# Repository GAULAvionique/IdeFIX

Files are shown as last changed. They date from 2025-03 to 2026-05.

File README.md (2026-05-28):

MasterHead (https://gaulspace.web.app/home)

<h1 align="center">Ordinateur de bord GAUL 2024-2025</h1>



<p align="left">
  <a href="https://www.facebook.com/gaul.ul" target="_blank">
    GAUL Facebook
  </a>
  <a href="https://www.instagram.com/gaul.ul/" target="_blank">
    GAUL Instagram
  </a>
  <a href="https://www.facebook.com/groupeaerospatialul/" target="_blank">
    GAUL Youtube
  </a>
</p>

## 🌟 **Projet IdeFIX**

IdeFIX est une **balise de repérage embarquée** développée par le GAUL afin de faciliter la récupération et le suivi d’équipements après mission. Le système agit comme une plateforme compacte de télémétrie et de localisation capable de transmettre des informations essentielles en temps réel.

Le projet est conçu pour être :

* Léger et robuste
* Facilement intégrable dans une charge utile ou une fusée
* Optimisé pour une faible consommation énergétique
* Modulable selon les besoins de mission

L’objectif principal d’IdeFIX est d’assurer un repérage fiable des systèmes embarqués pendant les phases de récupération à courte distance.

---

## 📦 **Fonctionnalités Intégrées**

Le système se subdivise en deux cartes qui peuvent inclure plusieurs modules matériels et logiciels :

* **Communication Radio**

  Transmission des données vers une station sol pour le suivi et la récupération.

* **Microcontrôleur principal**

  Assure le traitement des données, la gestion des capteurs et les communications.

* **Gestion d’alimentation**

  Système optimisé pour maximiser l’autonomie et assurer la stabilité électrique.

* **Indicateurs de statut**

  LEDs, buzzer ou autres systèmes de rétroaction pour le diagnostic et le déboggage.

---

## 🛰 **Architecture du Projet**

Le dépôt contient l’ensemble des éléments nécessaires au développement de la balise :

* Firmware embarqué
* Drivers matériels
* Configuration des périphériques
* Documentation technique
* Outils de test et validation
* Scripts utilitaires

L’architecture logicielle vise à simplifier le développement et permettre une maintenance efficace du système.

---

## 📷 **Images du Projet**

Découvrez les différentes itérations et prototypes de la balise de repérage :

[Voir la Showcase](./Documentation/Showcase.md)

<div style="display: flex; justify-content: space-around;">
  PCB IdeFIX
  Prototype IdeFIX
</div>

---

## 📚 **Documentation**

La documentation complète du projet est disponible dans le dossier `Documentation/`.

### Documentation matérielle

* [Composantes](./Documentation/Composantes.md)
* [Schémas](./Documentation/Schemas.md)
* [Assemblage](./Documentation/Assemblage.md)

### Documentation logicielle

* [Architecture logicielle](./Documentation/Architecture.md)
* [Drivers](./Documentation/Drivers.md)
* [Configuration](./Documentation/Configuration.md)
* [Prise en main](./Documentation/Logiciel.md)

### Développement

* [Guide de contribution](./Documentation/Contribution.md)
* [Tests et validation](./Documentation/Validation.md)

---

## ⚙ **Compilation et Déploiement**

Le projet est développé autour de l’écosystème STM32.

### Environnement recommandé

* STM32CubeIDE
* STM32CubeMX
* GCC ARM Toolchain

### Compilation

```bash
git clone https://github.com/GAULAvionique/IdeFIX.git
```

Ouvrir ensuite le projet dans STM32CubeIDE et compiler le firmware selon la configuration cible.

---

## 🛠 **Roadmap**

Fonctionnalités prévues et améliorations futures :

* Optimisation de la consommation énergétique
* Intégration LoRa longue portée
* Système de récupération automatique
* Interface de télémétrie améliorée
* Intégration de nouveaux capteurs
* Outils de visualisation des données

Consultez la [roadmap](./Documentation/Roadmap.md) pour plus de détails.

---

## 💡 **Liens Utiles**

* [STM32CubeIDE](https://www.st.com/en/development-tools/stm32cubeide.html)
* [Documentation STM32](https://www.st.com/)
* [Tutoriels STM32 — DeepBlueEmbedded](https://deepbluembedded.com/stm32-arm-programming-tutorials/)
* [GAUL](https://gaulspace.web.app/home)

---

## 👥 **Auteurs et Contributeurs**

* [@vides119](https://github.com/vides119)
* [@SamLol12](https://github.com/SamLol12)
* [Contributeurs GAUL](./Documentation/Participants.md)

---

🏠 Retour au la [page d'accueil](https://github.com/GAULAvionique2024-2025)

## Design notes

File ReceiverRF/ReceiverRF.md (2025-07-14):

## Repo technique pour le Receiver RF

Ce dossier contient tous les documents techniques relatifs à la conception du receiver RF.
Soit les librairies KiCad, les schématics KiCad, ainsi que le code.

TODO:
- [X] Footprint correct cristal ***
- [X] Logic converter 3V3 - 5V
- [X] UART out
- [X] Header correct
- [X] Remplacer header par connecteurs?
- [X] vrai interrupteur
- [X] Reverse polarity protection
- [X] Board essentiel + board interface
- [X] Vérifier alimentation

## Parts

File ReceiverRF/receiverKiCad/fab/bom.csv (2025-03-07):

Reference | Value | Digikey | Qty | DNP
Y1 | CTX853CT-ND | CTX853CT-ND | 1
U4 | MLX90393SLW-ABA-011-RE | MLX90393SLW-ABA-011-RECT-ND | 1
U3 | NJM2882F05-TE1 | 2129-NJM2882F05-TE1CT-ND | 1
U2 | NCV5501DT33RKG | NCV5501DT33RKGOSCT-ND | 1
U1 | STM32F103RET6 | 497-6444-ND | 1
S_R4 | 10R | RMCF1206FT10R0CT-ND | 1
RV1 | RK09K1130A5R | PTV09A-4025S-A103-ND | 1
Q1 | MMBT3904 | MMBT3904LT1GOSCT-ND | 1
PWR_D1,PWR_D2 | LTST-C190EKT | 160-1182-1-ND | 2
PWR_C5,S_C7 | 10nF | 311-1174-1-ND | 2
PWR_C2 | 4.7uF | 1276-3182-1-ND | 1
PWR_C1,STM_C6 | 10uF | 2679-AGC1206X6S250-106KXETR-ND | 2
MLX_C3,PWR_C3,STM_C8,STM_C9 | 1uF | 1276-1068-1-ND | 4
MLX_C1,MLX_C2,PWR_C4,STM_C1,STM_C3,STM_C4,STM_C5,S_C2,S_C10 | 100nF | 399-C1206C104K5RACTUCT-ND | 9
LED_R1,LED_R2,LED_R3,PWR_R1,PWR_R2,PWR_R3,PWR_R4 | 145R | 2019-RN73H2BTTD1450F100CT-ND | 7
J1 | RF2-03E-T-00-50-G | 2057-RF2-03E-T-00-50-G-ND | 1
FB1 | ILBB0603ER121V | 541-2290-1-ND | 1
D1,D2,D3 | LTST-C170GKT | 160-1179-1-ND | 3
CSTL_C1,CSTL_C2 | 16pF | 399-CBR06C160F5GACCT-ND | 2
BZ1 | SMTB-0927-TW-R | 668-SMTB-0927-TW-RCT-ND | 1
BUZ_R2,STM_R2 | 1k5 | 541-4184-1-ND | 2
BUZ_R1 | 50R | 541-TNPW120650R0BEENCT-ND | 1
BUZ_D1 | BAT54T1G | BAT54T1GOSCT-ND | 1
BUT_R1,BUT_R2,BUT_R4,I2C_R1,I2C_R2,MLX_R1,MLX_R2,STM_R3,S_R1 | 10k | 311-10.0KFRCT-ND | 9

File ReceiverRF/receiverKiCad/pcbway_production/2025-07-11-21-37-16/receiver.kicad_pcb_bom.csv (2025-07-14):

Designator | Quantity | Value | Footprint | Package | MPN | DNP | Mount_Type | Digikey | Description | Sim.Device | Sim.Type | Sim.Pins
BUT_R1, BUT_R2, BUT_R3, BUT_R4, I2C_R1, I2C_R2, LLS_R2, MLX_R1, MLX_R2, STM_R3, S_R1 | 11 | 10k | R_1206_3216Metric |  |  |  | smt | 311-10.0KFRCT-ND
BUZ_D1 | 1 | BAT54T1G | D_SOD-123 |  |  |  | smt | BAT54T1GOSCT-ND
BUZ_R1 | 1 | 50R | R_1206_3216Metric |  |  |  | smt | 541-TNPW120650R0BEENCT-ND
BUZ_R2, STM_R2 | 2 | 1k5 | R_1206_3216Metric |  |  |  | smt | 541-4184-1-ND
BZ1 | 1 | SMTB-0927-TW-R | Buzzer_D14mm_H7mm_P10mm |  |  |  | tht | 668-SMTB-0927-TW-RCT-ND | SMTB-0927-TW-R
CSTL_C1, CSTL_C2 | 2 | 16pF | C_0603_1608Metric_Pad1.08x0.95mm_HandSolder |  |  |  | smt | 399-CBR06C160F5GACCT-ND
D1 | 1 | SZMMSZ4679T1G | D_MiniMELF |  |  |  | smt | SZMMSZ4679T1GOSCT-ND | 18V, 500mW, 5%, Zener diode, MiniMELF
D2, D3, D4 | 3 | LTST-C170GKT | LTST-C170GKT |  |  |  | smt | 160-1179-1-ND
FB1 | 1 | ILBB0603ER121V | Ferrite_0603 |  |  |  | smt | 541-2290-1-ND | 120 ohm @ 100 MHz
HOLES1, HOLES2 | 2 | Mounting_holes | Mounting_holes |  |  |  | smt
HOLES3 | 1 | Mounting_holes_big | Mounting_holes_big |  |  |  | smt
IF1, IF2 | 2 | ~ | CONN10_530481010_MOL |  |  |  | tht | WM1750-ND
J1 | 1 | RF2-03E-T-00-50-G | SMA_90deg |  |  |  | tht | 2057-RF2-03E-T-00-50-G-ND
J2 | 1 | Conn_01x05_Socket | PinHeader_1x05_P2.54mm_Vertical |  |  |  | tht
J3 | 1 | Conn_01x02_Socket | PinHeader_1x02_P2.54mm_Vertical |  |  |  | tht |  | Generic connector, single row, 01x02, script generated
J4 | 1 | Conn_01x04 | PinHeader_1x04_P2.54mm_Vertical |  |  |  | tht
JP1 | 1 | SolderJumper_2_Open | SolderJumper-2_P1.3mm_Open_TrianglePad1.0x1.5mm |  |  |  | tht
LED_R1, LED_R2, LED_R3, PWR_R1, PWR_R2, PWR_R3, PWR_R4 | 7 | 145R | R_1206_3216Metric |  |  |  | smt | 2019-RN73H2BTTD1450F100CT-ND
LLS_C1, LLS_C2, MLX_C1, MLX_C2, PWR_C4, STM_C1, STM_C3, STM_C4, STM_C5, S_C10, S_C2 | 11 | 100nF | C_1206_3216Metric |  |  |  | smt | 399-C1206C104K5RACTUCT-ND
MLX_A0, MLX_A1 | 2 | jumper | SolderJumper-2_P1.3mm_Open_TrianglePad1.0x1.5mm |  |  |  | tht
MLX_C3, PWR_C3, STM_C8, STM_C9 | 4 | 1uF | C_1206_3216Metric |  |  |  | smt | 1276-1068-1-ND
PWR_C1, STM_C6 | 2 | 10uF | C_1206_3216Metric |  |  |  | smt | 2679-AGC1206X6S250-106KXETR-ND
PWR_C2 | 1 | 4.7uF | C_1206_3216Metric |  |  |  | smt | 1276-3182-1-ND
PWR_C5, S_C7 | 2 | 10nF | C_1206_3216Metric |  |  |  | smt | 311-1174-1-ND
PWR_D1, PWR_D2 | 2 | LTST-C190EKT | LTST-C190EKT |  |  |  | smt | 160-1182-1-ND
PWR_J1 | 1 | Conn_01x02 | PinHeader_1x02_P2.54mm_Vertical |  |  |  | tht
PWR_R5 | 1 | 100k | R_1206_3216Metric |  |  |  | smt | 541-100KUTR-ND
Q1 | 1 | MMBT3904 | SOT-23 |  |  |  | smt | MMBT3904LT1GOSCT-ND | MMBT3904 | NPN | GUMMELPOON | 1=C 2=B 3=E
Q2 | 1 | NTR4101PT1G | SOT-23 |  |  |  | smt | NTR4101PT1GOSCT-ND | P-MOSFET transistor, drain/source/gate | PMOS | VDMOS | 1=D 2=G 3=S
RF1 | 1 | RFM22B | RFM22b-S2_TH |  |  |  | smt
RV1 | 1 | RK09K1130A5R | Potentiometer_Alps_RK09K_Single_Vertical |  |  |  | tht | PTV09A-4025S-A103-ND | RK09K1130A5R
SW1, SW2, SW3, SW4 | 4 | SW_Push | SW_PUSH_6mm_H4.3mm |  |  |  | tht | EG1862-ND
SW5 | 1 | SW_SPDT | CS12ANW03_NKK |  |  |  | tht | 360-2131-ND | Switch, single pole double throw
S_R4 | 1 | 10R | R_1206_3216Metric |  |  |  | smt | RMCF1206FT10R0CT-ND
U1 | 1 | STM32F103RET6 | LQFP64-10x10mm |  |  |  | smt | 497-6444-ND
U2 | 1 | NCV5501DT33RKG | DPAK-3_ONS-M |  |  |  | smt | NCV5501DT33RKGOSCT-ND
U3 | 1 | NJM2882F05-TE1 | SOT-23-5 |  |  |  | smt | 2129-NJM2882F05-TE1CT-ND
U4 | 1 | MLX90393SLW-ABA-011-RE | QFN-16_MLX90393_MEL-L |  |  |  | smt | MLX90393SLW-ABA-011-RECT-ND
U5 | 1 | TXS0102DCUR | SOP50P310X90-8N |  |  |  | smt | 296-21931-2-ND
Y1 | 1 | CTX853CT-ND | Crystal |  |  |  | smt | CTX853CT-ND | 406C35D08M00000

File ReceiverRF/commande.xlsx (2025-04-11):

NOM | I (mA) | QTE | PRIX | DESCRIPTION | LIEN | Coût total
MLX90393 | 1.75 | 1 | 2.85 | bousolle | https://www.digikey.com/en/products/detail/melexis-technologies-nv/MLX90393SLW-ABA-011-RE/5031684 | 100.88453
RFM22B-S2 | 18.5 | 2 | 18.52 | transceiver rf | https://www.xonelec.com/mpn/hopemicroelectronics/rfm22b433s2 | .
STM32F103RET6 | 150 | 1 | 17.33 | MCU | https://www.digikey.ca/en/products/detail/stmicroelectronics/STM32F103RET6/1852094?gad_source=1 | .
NCV5501DT33RKG | -500 | 1 | 1.53 | régulateur 3,3V | https://www.digikey.ca/en/products/detail/onsemi/NCV5501DT33RKG/1792725 | .
NJM2882F05 | 300 | 1 | 1.1 | régulateur 5V | https://www.digikey.ca/en/products/detail/nisshinbo-micro-devices-inc/NJM2882F05-TE1/10671911 | .
CN0296D | 100 | 1 | 20.82 | écran LCD | https://www.digikey.ca/en/products/detail/sunfounder/CN0296D/18668625?gad_source=1 | .
SMTB-0927-TW-R | 80 | 1 | 1.27 | buzzer | https://www.digikey.com/en/products/detail/pui-audio-inc/SMTB-0927-TW-R/13165907 | .
LTST-C170GKT | 10 | 3 | 0.24 | led verte | https://www.digikey.com/en/products/detail/liteon/LTST-C170GKT/269226 | .
LTST-C190EKT | 10 | 2 | 0.34 | led rouge | https://www.digikey.ca/en/products/detail/liteon/LTST-C190EKT/269229?productid=&gad_source=1 | .
L101011MS02Q |  | 1 | 3.73 | interrupteur on/off | https://www.digikey.ca/en/products/detail/c-k/L101011MS02Q/484142 | .
PTV09A-4025S-A103 |  | 1 | 1.09 | potentiomètre | https://www.digikey.ca/en/products/detail/bourns-inc/PTV09A-4025S-A103/3820578 | .
TL1105T | 6 | 4 |  | bouton | https://www.digikey.ca/en/products/detail/c-k/D102J12S215PQA/768267 | .
ILBB0603ER121V | 150 | 1 | 0.16 | ferrite bead | https://www.digikey.ca/en/products/detail/vishay-dale/ILBB0603ER121V/2574888 | .
YG8M000000S418 |  | 1 | 1.85 | Cristal 8MHz | https://www.digikey.ca/en/products/detail/nextgen-components/YG8M000000S418/17289334 | .
RF2-03E-T-00-50-G |  | 1 | 4.19 | Connecteur SMA 90deg | https://www.digikey.ca/en/products/detail/adam-tech/RF2-03E-T-00-50-G/9831386 | .
MMBT3904 |  | 1 | 0.12 | Transistor NPN | https://www.digikey.ca/en/products/detail/onsemi/MMBT3904LT1G/1139813 | .
BAT54T1G |  | 1 | 0.13 | Diode schottky | https://www.digikey.ca/en/products/detail/onsemi/BAT54T1G/918319 | .
 |  |  |  |  |  | .
 |  | 1 | 0.28 | cond 4,7u | https://www.digikey.ca/en/products/detail/samsung-electro-mechanics/CL31B475KOHNNNE/3888840 | . | 1206(3216)
 |  | 2 | 0.09306 | cond 10u | https://www.digikey.ca/en/products/detail/venkel/AGC1206X6S250-106KXE/20484934 | . | 1206(3216)
 |  | 4 | 0.01806 | cond 1u | https://www.digikey.ca/en/products/detail/samsung-electro-mechanics/CL31B105KBHNNNE/3886726 | . | 1206(3216)
 |  | 9 | 0.00805 | cond 100n | https://www.digikey.ca/en/products/detail/kemet/C1206C104K5RACTU/411248 | . | 1206(3216)
 |  | 2 | 0.00186 | cond 10n | https://www.digikey.ca/en/products/detail/yageo/CC1206KRX7R9BB103/302908 | . | 1206(3216)
 |  | 2 | 0.33 | cond 16p | https://www.digikey.ca/en/products/detail/kemet/CBR06C160F5GAC/3473742 | . | 0603(1608)
 |  |  |  |  |  | .
 |  | 9 | 0.1 | res 10k | https://www.digikey.ca/en/products/detail/yageo/RC1206FR-0710KL/728483 | . | 1206(3216)
 |  | 1 | 0.1 | res 10 | https://www.digikey.ca/en/products/detail/stackpole-electronics-inc/RMCF1206FT10R0/1759594 | . | 1206(3216)
 |  | 1 | 0.91 | res 50 (100mA) | https://www.digikey.ca/en/products/detail/vishay-dale/TNPW120650R0BEEN/21556504 | . | 1206(3216)
 |  | 2 | 0.18 | res 1k5 | https://www.digikey.ca/en/products/detail/vishay-dale/CRCW12061K50FKEAC/7928606 | . | 1206(3216)
 |  | 7 | 0.39 | res 145 (50mA) | https://www.digikey.ca/en/products/detail/koa-speer-electronics-inc/RN73H2BTTD1450F100/10092754 | . | 1206(3216)
 |  |  |  |  |  | .
 |  |  |  |  |  | .
 |  |  |  |  |  | .
 |  |  |  |  |  | .
 |  |  |  |  |  | .
 |  |  |  |  |  | .
 |  |  |  |  |  | .
 |  |  |  |  |  | .

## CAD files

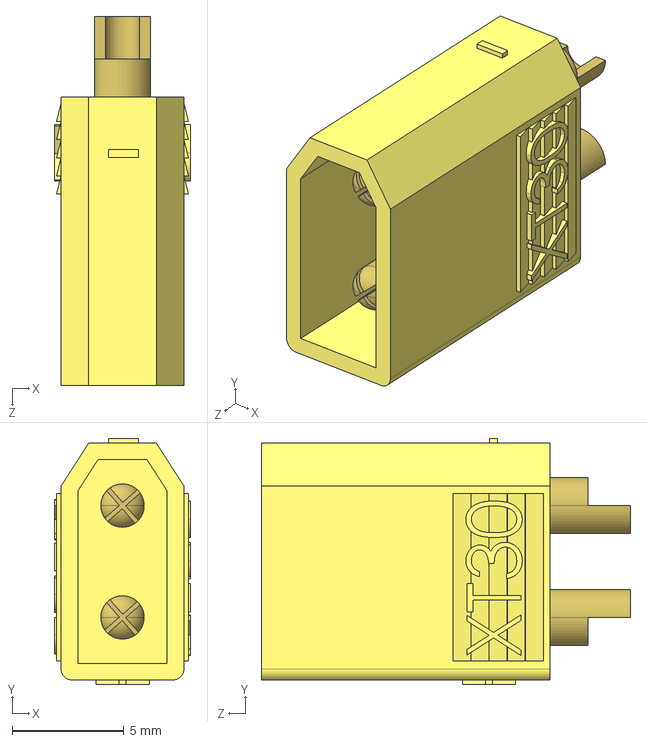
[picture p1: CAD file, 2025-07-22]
ReceiverRF/receiverKiCad/librairie-receiver/lib_3D/XT30-M_m.ver.STEP
6.10 x 11.0 x 16.5 mm

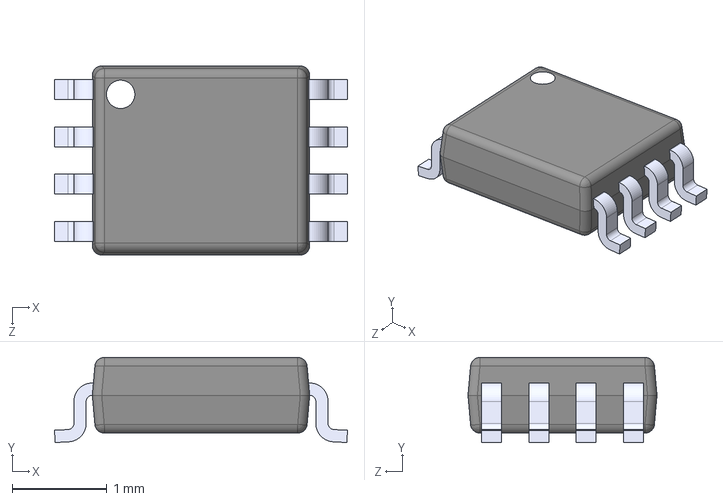
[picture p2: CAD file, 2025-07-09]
ReceiverRF/receiverKiCad/librairie-receiver/lib_3D/TXS0102DCUR.step
3.10 x 0.9 x 2.00 mm

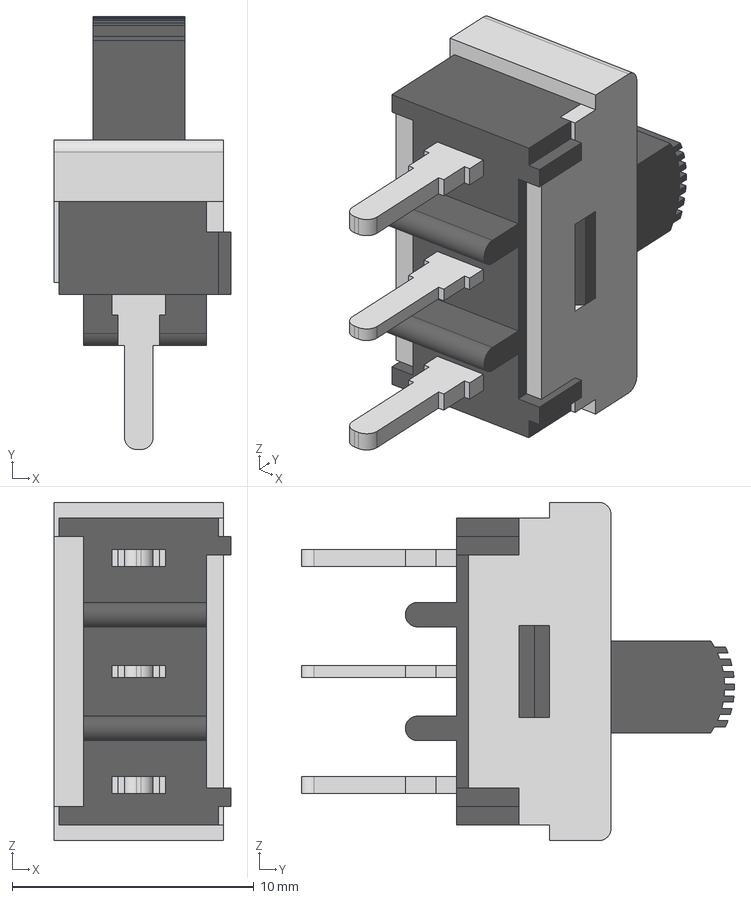
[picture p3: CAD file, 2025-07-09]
ReceiverRF/receiverKiCad/librairie-receiver/lib_3D/CS12ANW03.stp
7.32 x 17.9 x 14.0 mm
CS12ANW03-body
CS12ANW03-top
CS12ANW03-term
CS12ANW03-slide

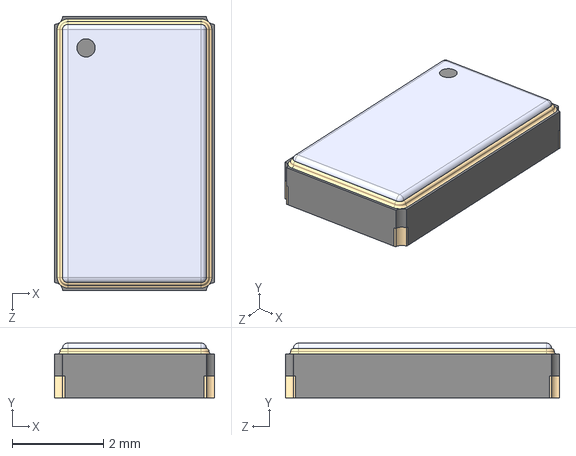
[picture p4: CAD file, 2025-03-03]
ReceiverRF/receiverKiCad/librairie-receiver/lib_3D/406C35D08M00000.STEP
3.50 x 1.20 x 6.00 mm

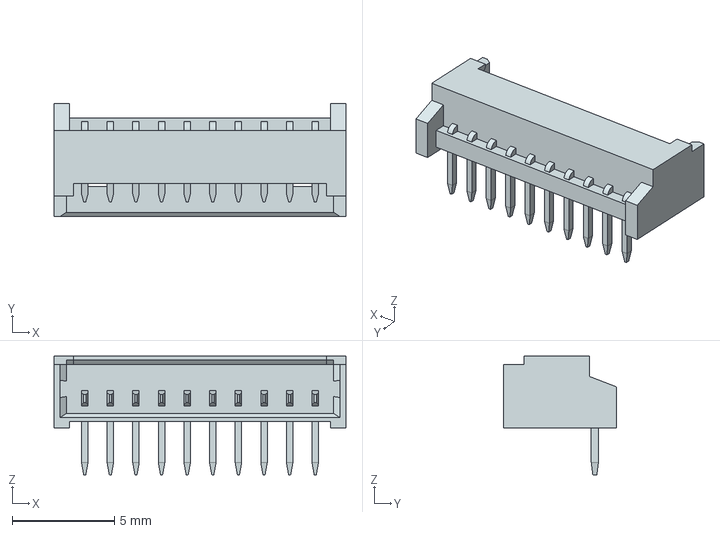
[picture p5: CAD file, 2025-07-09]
ReceiverRF/receiverKiCad/librairie-receiver/lib_3D/530481010.stp
14.2 x 5.50 x 5.80 mm

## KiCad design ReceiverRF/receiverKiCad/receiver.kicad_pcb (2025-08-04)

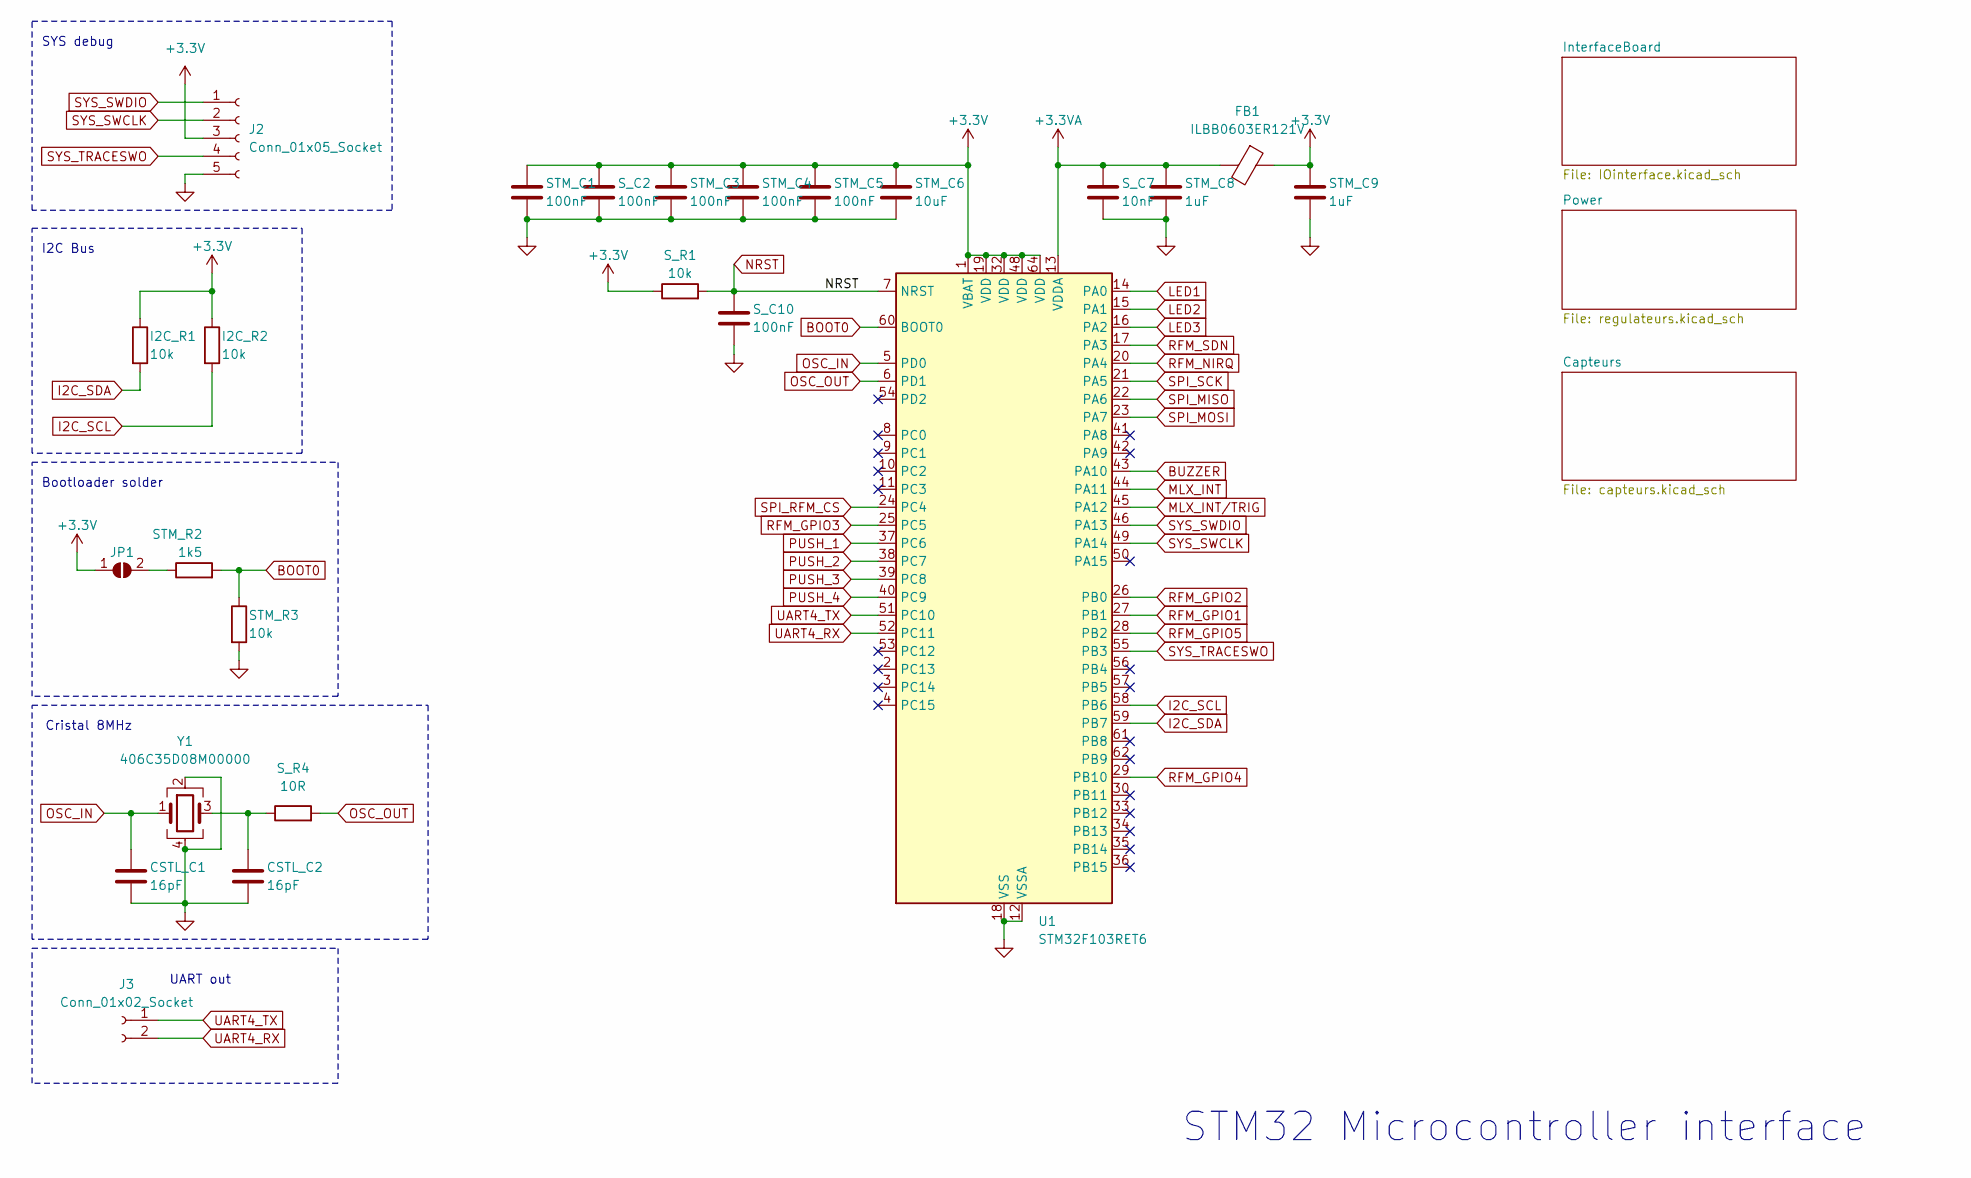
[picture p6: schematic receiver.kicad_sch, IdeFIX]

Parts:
CSTL_C1, CSTL_C2: 16pF; C_0603_1608Metric_Pad1.08x0.95mm_HandSolder; Digikey 399-CBR06C160F5GACCT-ND
FB1: ILBB0603ER121V; Ferrite_0603; Digikey 541-2290-1-ND
I2C_R1, I2C_R2: 10k; R_1206_3216Metric; Digikey 311-10.0KFRCT-ND
J2: Conn_01x05_Socket; PinHeader_1x05_P2.54mm_Vertical
J3: Conn_01x02_Socket; PinHeader_1x02_P2.54mm_Vertical
JP1: SolderJumper_2_Open; SolderJumper-2_P1.3mm_Open_TrianglePad1.0x1.5mm
STM_C1, STM_C3, STM_C4, STM_C5: 100nF; C_1206_3216Metric; Digikey 399-C1206C104K5RACTUCT-ND
STM_C6: 10uF; C_1206_3216Metric; Digikey 1276-1804-1-ND
STM_C8, STM_C9: 1uF; C_1206_3216Metric; Digikey 1276-1068-1-ND
STM_R2: 1k5; R_1206_3216Metric; Digikey 541-4184-1-ND
STM_R3: 10k; R_1206_3216Metric; Digikey 311-10.0KFRCT-ND
S_C2, S_C10: 100nF; C_1206_3216Metric; Digikey 399-C1206C104K5RACTUCT-ND
S_C7: 10nF; C_1206_3216Metric; Digikey 311-1174-1-ND
S_R1: 10k; R_1206_3216Metric; Digikey 311-10.0KFRCT-ND
S_R4: 10R; R_1206_3216Metric; Digikey RMCF1206FT10R0CT-ND
U1: STM32F103RET6; LQFP64-10x10mm; Digikey 497-6444-ND
Y1: 406C35D08M00000; Crystal; Digikey 110-406C35D08M00000CT-ND

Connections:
+3.3V: FB1.1, I2C_R1.1, I2C_R2.1, J2.3, JP1.1 (A), STM_C1.1, STM_C3.1, STM_C4.1, STM_C5.1, STM_C6.1, STM_C9.1, S_C2.1, S_R1.1, U1.1 (VBAT), U1.19 (VDD), U1.32 (VDD), U1.48 (VDD), U1.64 (VDD); also elsewhere on the board
+3.3VA: FB1.2, STM_C8.1, S_C7.1, U1.13 (VDDA)
BOOT0: STM_R2.2, STM_R3.1, U1.60 (BOOT0)
BUZZER: U1.43 (PA10); also elsewhere on the board
GND: CSTL_C1.2, CSTL_C2.2, J2.5, STM_C1.2, STM_C3.2, STM_C4.2, STM_C5.2, STM_C6.2, STM_C8.2, STM_C9.2, STM_R3.2, S_C2.2, S_C7.2, S_C10.2, U1.12 (VSSA), U1.18 (VSS), U1.31 (VSS), U1.47 (VSS), U1.63 (VSS), Y1.2, Y1.4; also elsewhere on the board
I2C_SCL: I2C_R2.2, U1.58 (PB6); also elsewhere on the board
I2C_SDA: I2C_R1.2, U1.59 (PB7); also elsewhere on the board
LED1: U1.14 (PA0); also elsewhere on the board
LED2: U1.15 (PA1); also elsewhere on the board
LED3: U1.16 (PA2); also elsewhere on the board
MLX_INT: U1.44 (PA11); also elsewhere on the board
MLX_INT/TRIG: U1.45 (PA12); also elsewhere on the board
NRST: S_C10.1, S_R1.2, U1.7 (NRST)
unnamed: CSTL_C2.1, S_R4.1, Y1.3
unnamed: JP1.2 (B), STM_R2.1
OSC_IN: CSTL_C1.1, U1.5 (PD0), Y1.1
OSC_OUT: S_R4.2, U1.6 (PD1)
PUSH_1: U1.37 (PC6); also elsewhere on the board
PUSH_2: U1.38 (PC7); also elsewhere on the board
PUSH_3: U1.39 (PC8); also elsewhere on the board
PUSH_4: U1.40 (PC9); also elsewhere on the board
RFM_GPIO1: U1.27 (PB1); also elsewhere on the board
RFM_GPIO2: U1.26 (PB0); also elsewhere on the board
RFM_GPIO3: U1.25 (PC5); also elsewhere on the board
RFM_GPIO4: U1.29 (PB10); also elsewhere on the board
RFM_GPIO5: U1.28 (PB2); also elsewhere on the board
RFM_NIRQ: U1.20 (PA4); also elsewhere on the board
RFM_SDN: U1.17 (PA3); also elsewhere on the board
SPI_MISO: U1.22 (PA6); also elsewhere on the board
SPI_MOSI: U1.23 (PA7); also elsewhere on the board
SPI_RFM_CS: U1.24 (PC4); also elsewhere on the board
SPI_SCK: U1.21 (PA5); also elsewhere on the board
SYS_SWCLK: J2.2, U1.49 (PA14)
SYS_SWDIO: J2.1, U1.46 (PA13)
SYS_TRACESWO: J2.4, U1.55 (PB3)
UART4_RX: J3.2, U1.52 (PC11)
UART4_TX: J3.1, U1.51 (PC10)

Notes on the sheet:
I2C Bus
STM32 Microcontroller interface
Cristal 8MHz
Bootloader solder
SYS debug
UART out

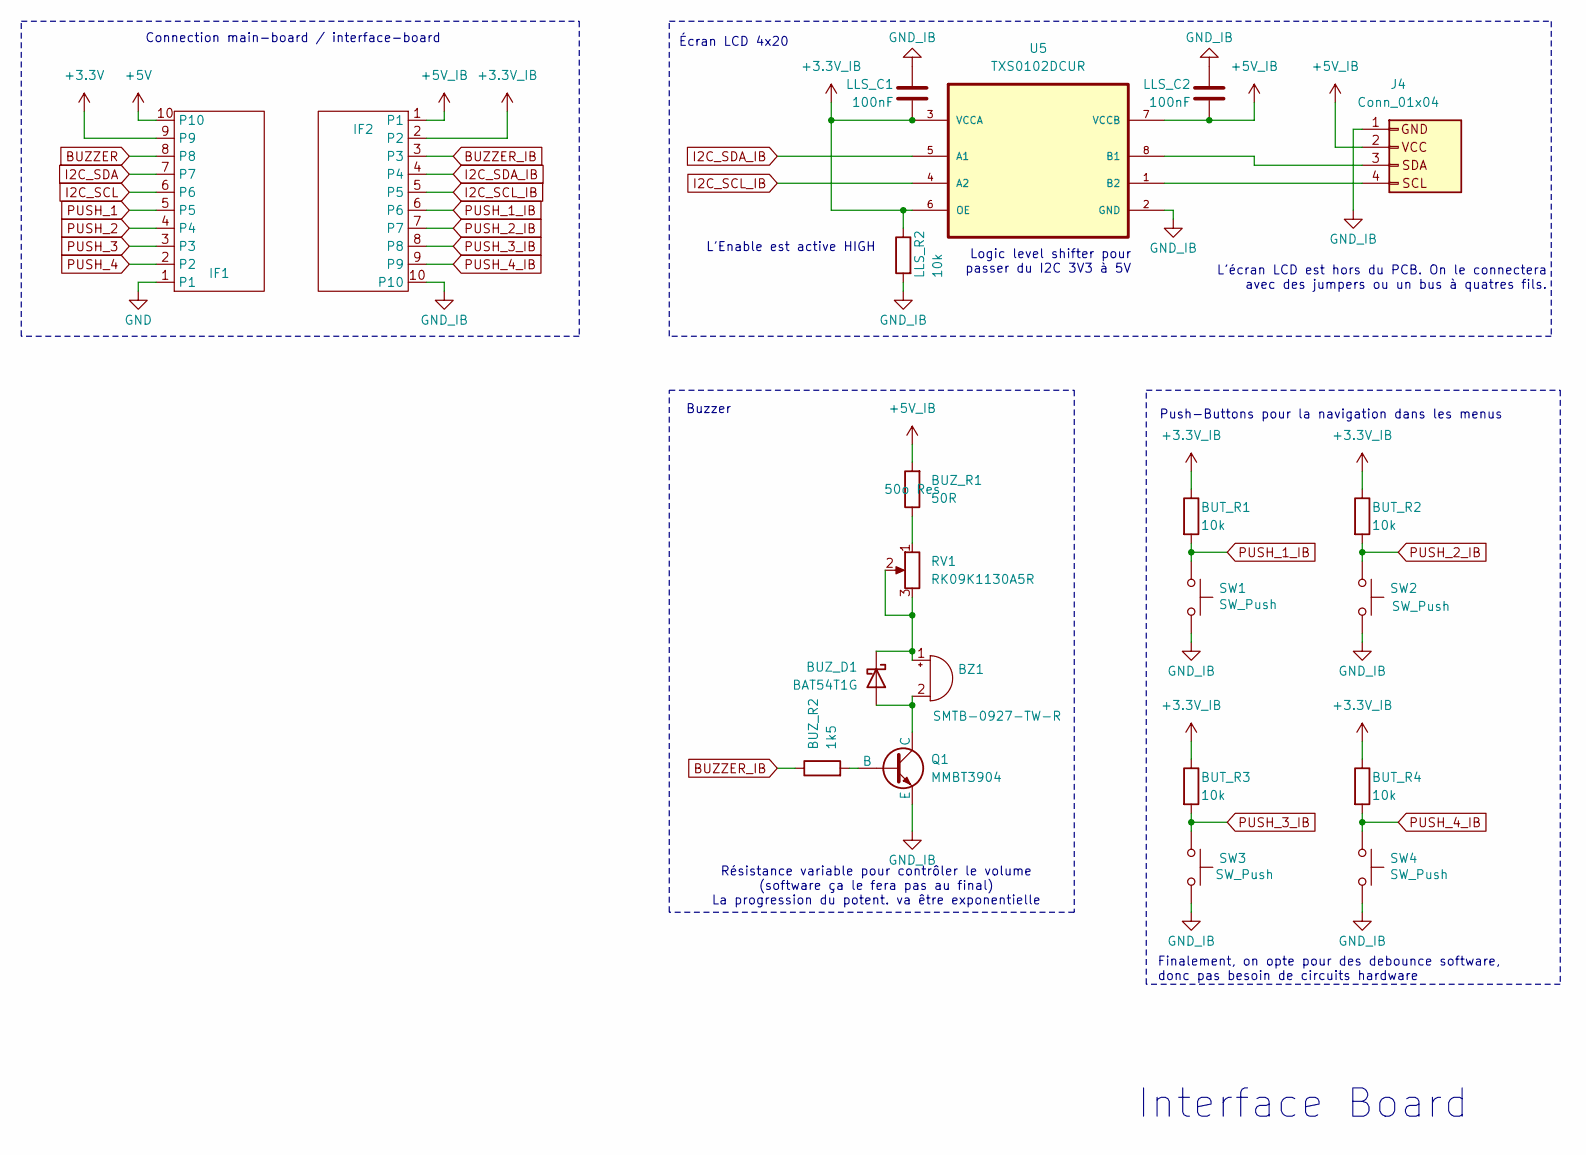
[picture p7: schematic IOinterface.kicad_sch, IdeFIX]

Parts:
BUT_R1, BUT_R2, BUT_R3, BUT_R4: 10k; R_1206_3216Metric; Digikey 311-10.0KFRCT-ND
BUZ_D1: BAT54T1G; D_SOD-123; Digikey BAT54T1GOSCT-ND
BUZ_R1: 50R; R_1206_3216Metric; Digikey 541-TNPW120650R0BEENCT-ND
BUZ_R2: 1k5; R_1206_3216Metric; Digikey 541-4184-1-ND
BZ1: SMTB-0927-TW-R; Buzzer_D14mm_H7mm_P10mm; Digikey 668-SMTB-0927-TW-RCT-ND
IF1, IF2: CONN10_530481010_MOL; Digikey WM1750-ND
J4: Conn_01x04; PinHeader_1x04_P2.54mm_Vertical
LLS_C1, LLS_C2: 100nF; C_1206_3216Metric; Digikey 399-C1206C104K5RACTUCT-ND
LLS_R2: 10k; R_1206_3216Metric; Digikey 311-10.0KFRCT-ND
Q1: MMBT3904; SOT-23; Digikey MMBT3904LT1GOSCT-ND
RV1: RK09K1130A5R; Potentiometer_Alps_RK09K_Single_Vertical; Digikey 4809-RK09K1130A5R-ND
SW1, SW2, SW3, SW4: SW_Push; SW_PUSH_6mm_H4.3mm; Digikey EG1862-ND
U5: TXS0102DCUR; SOP50P310X90-8N; Digikey 296-21931-2-ND

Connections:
+3.3V: IF1.9; also elsewhere on the board
+3.3V_IB: BUT_R1.1, BUT_R2.1, BUT_R3.1, BUT_R4.1, IF2.2, LLS_C1.2, LLS_R2.1, U5.3 (VCCA), U5.6 (OE)
+5V: IF1.10; also elsewhere on the board
+5V_IB: BUZ_R1.2, IF2.1, J4.2 (VCC), LLS_C2.2, U5.7 (VCCB)
BUZZER: IF1.8; also elsewhere on the board
BUZZER_IB: BUZ_R2.1, IF2.3
GND: IF1.1; also elsewhere on the board
GND_IB: IF2.10, J4.1 (GND), LLS_C1.1, LLS_C2.1, LLS_R2.2, Q1.3 (E), SW1.2, SW2.2, SW3.2, SW4.2, U5.2 (GND)
I2C_SCL: IF1.6; also elsewhere on the board
I2C_SCL_IB: IF2.5, U5.4 (A2)
I2C_SDA: IF1.7; also elsewhere on the board
I2C_SDA_IB: IF2.4, U5.5 (A1)
unnamed: BUZ_D1.2 (A), BZ1.2 (+), Q1.1 (C)
unnamed: BUZ_D1.1 (K), BZ1.1 (-), RV1.2, RV1.3
unnamed: BUZ_R1.1, RV1.1
unnamed: J4.4 (SCL), U5.1 (B2)
unnamed: J4.3 (SDA), U5.8 (B1)
unnamed: BUZ_R2.2, Q1.2 (B)
PUSH_1: IF1.5; also elsewhere on the board
PUSH_1_IB: BUT_R1.2, IF2.6, SW1.1
PUSH_2: IF1.4; also elsewhere on the board
PUSH_2_IB: BUT_R2.2, IF2.7, SW2.1
PUSH_3: IF1.3; also elsewhere on the board
PUSH_3_IB: BUT_R3.2, IF2.8, SW3.1
PUSH_4: IF1.2; also elsewhere on the board
PUSH_4_IB: BUT_R4.2, IF2.9, SW4.1

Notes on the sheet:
Logic level shifter pour passer du I2C 3V3 à 5V
Interface Board
Connection main-board / interface-board
L'écran LCD est hors du PCB. On le connectera avec des jumpers ou un bus à quatres fils.
Finalement, on opte pour des debounce software, donc pas besoin de circuits hardware
Écran LCD 4x20
Résistance variable pour contrôler le volume (software ça le fera pas au final) La progression du potent. va être exponentielle
Buzzer
Push-Buttons pour la navigation dans les menus
L'Enable est active HIGH

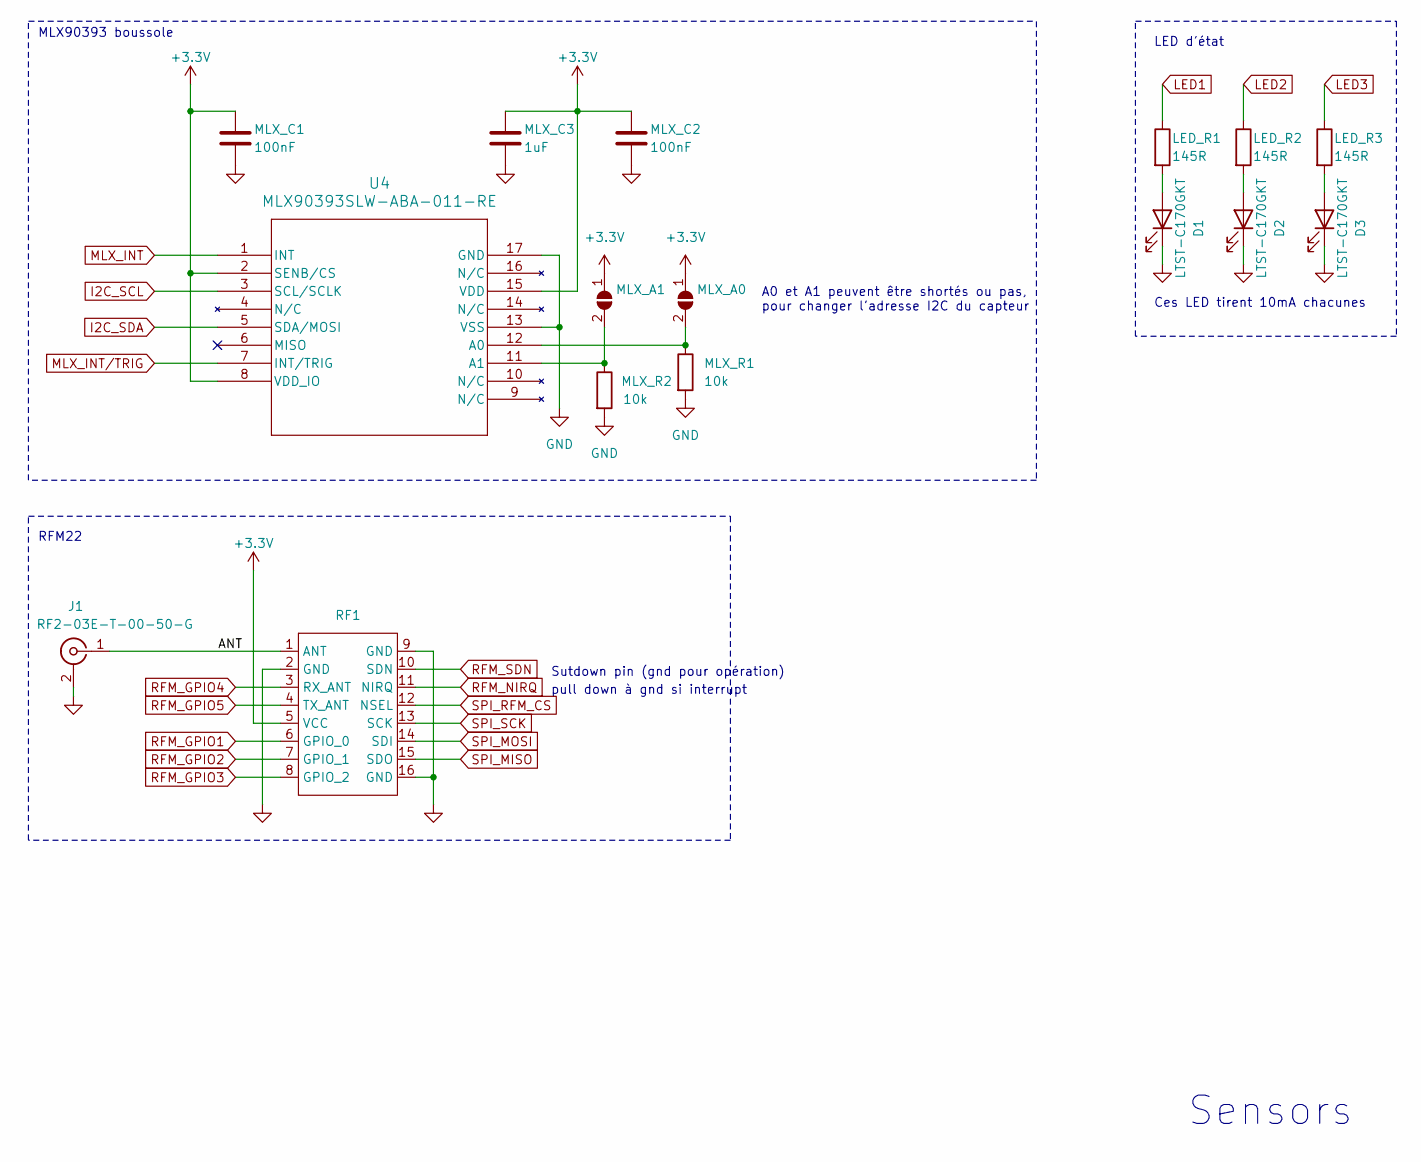
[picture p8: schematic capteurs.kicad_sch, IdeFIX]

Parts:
D1, D2, D3: LTST-C170GKT; Digikey 160-1414-1-ND
J1: RF2-03E-T-00-50-G; SMA_90deg; Digikey 2057-RF2-03E-T-00-50-G-ND
LED_R1, LED_R2, LED_R3: 145R; R_1206_3216Metric; Digikey 2019-RN73H2BTTD1450F100CT-ND
MLX_A0, MLX_A1: jumper; SolderJumper-2_P1.3mm_Open_TrianglePad1.0x1.5mm
MLX_C1, MLX_C2: 100nF; C_1206_3216Metric; Digikey 399-C1206C104K5RACTUCT-ND
MLX_C3: 1uF; C_1206_3216Metric; Digikey 1276-1068-1-ND
MLX_R1, MLX_R2: 10k; R_1206_3216Metric; Digikey 311-10.0KFRCT-ND
RF1: RFM22B; RFM22b-S2_TH
U4: MLX90393SLW-ABA-011-RE; QFN-16_MLX90393_MEL-L; Digikey MLX90393SLW-ABA-011-RECT-ND

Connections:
+3.3V: MLX_A0.1 (A), MLX_A1.1 (A), MLX_C1.1, MLX_C2.1, MLX_C3.1, RF1.5 (VCC), U4.2 (SENB/CS), U4.8 (VDD_IO), U4.15 (VDD); also elsewhere on the board
/Capteurs/ANT: J1.1 (In), RF1.1 (ANT)
GND: D1.1 (K), D2.1 (K), D3.1 (K), J1.2 (Ext), MLX_C1.2, MLX_C2.2, MLX_C3.2, MLX_R1.2, MLX_R2.2, RF1.2 (GND), RF1.9 (GND), RF1.16 (GND), U4.13 (VSS), U4.17 (GND); also elsewhere on the board
I2C_SCL: U4.3 (SCL/SCLK); also elsewhere on the board
I2C_SDA: U4.5 (SDA/MOSI); also elsewhere on the board
LED1: LED_R1.1; also elsewhere on the board
LED2: LED_R2.1; also elsewhere on the board
LED3: LED_R3.1; also elsewhere on the board
MLX_INT: U4.1 (INT); also elsewhere on the board
MLX_INT/TRIG: U4.7 (INT/TRIG); also elsewhere on the board
unnamed: D1.2 (A), LED_R1.2
unnamed: D2.2 (A), LED_R2.2
unnamed: D3.2 (A), LED_R3.2
unnamed: MLX_A0.2 (B), MLX_R1.1, U4.12 (A0)
unnamed: MLX_A1.2 (B), MLX_R2.1, U4.11 (A1)
RFM_GPIO1: RF1.6 (GPIO_0); also elsewhere on the board
RFM_GPIO2: RF1.7 (GPIO_1); also elsewhere on the board
RFM_GPIO3: RF1.8 (GPIO_2); also elsewhere on the board
RFM_GPIO4: RF1.3 (RX_ANT); also elsewhere on the board
RFM_GPIO5: RF1.4 (TX_ANT); also elsewhere on the board
RFM_NIRQ: RF1.11 (NIRQ); also elsewhere on the board
RFM_SDN: RF1.10 (SDN); also elsewhere on the board
SPI_MISO: RF1.15 (SDO); also elsewhere on the board
SPI_MOSI: RF1.14 (SDI); also elsewhere on the board
SPI_RFM_CS: RF1.12 (NSEL); also elsewhere on the board
SPI_SCK: RF1.13 (SCK); also elsewhere on the board

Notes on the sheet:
Ces LED tirent 10mA chacunes
pull down à gnd si interrupt
Sutdown pin (gnd pour opération)
MLX90393 boussole
LED d'état
Sensors
RFM22
A0 et A1 peuvent être shortés ou pas, pour changer l'adresse I2C du capteur

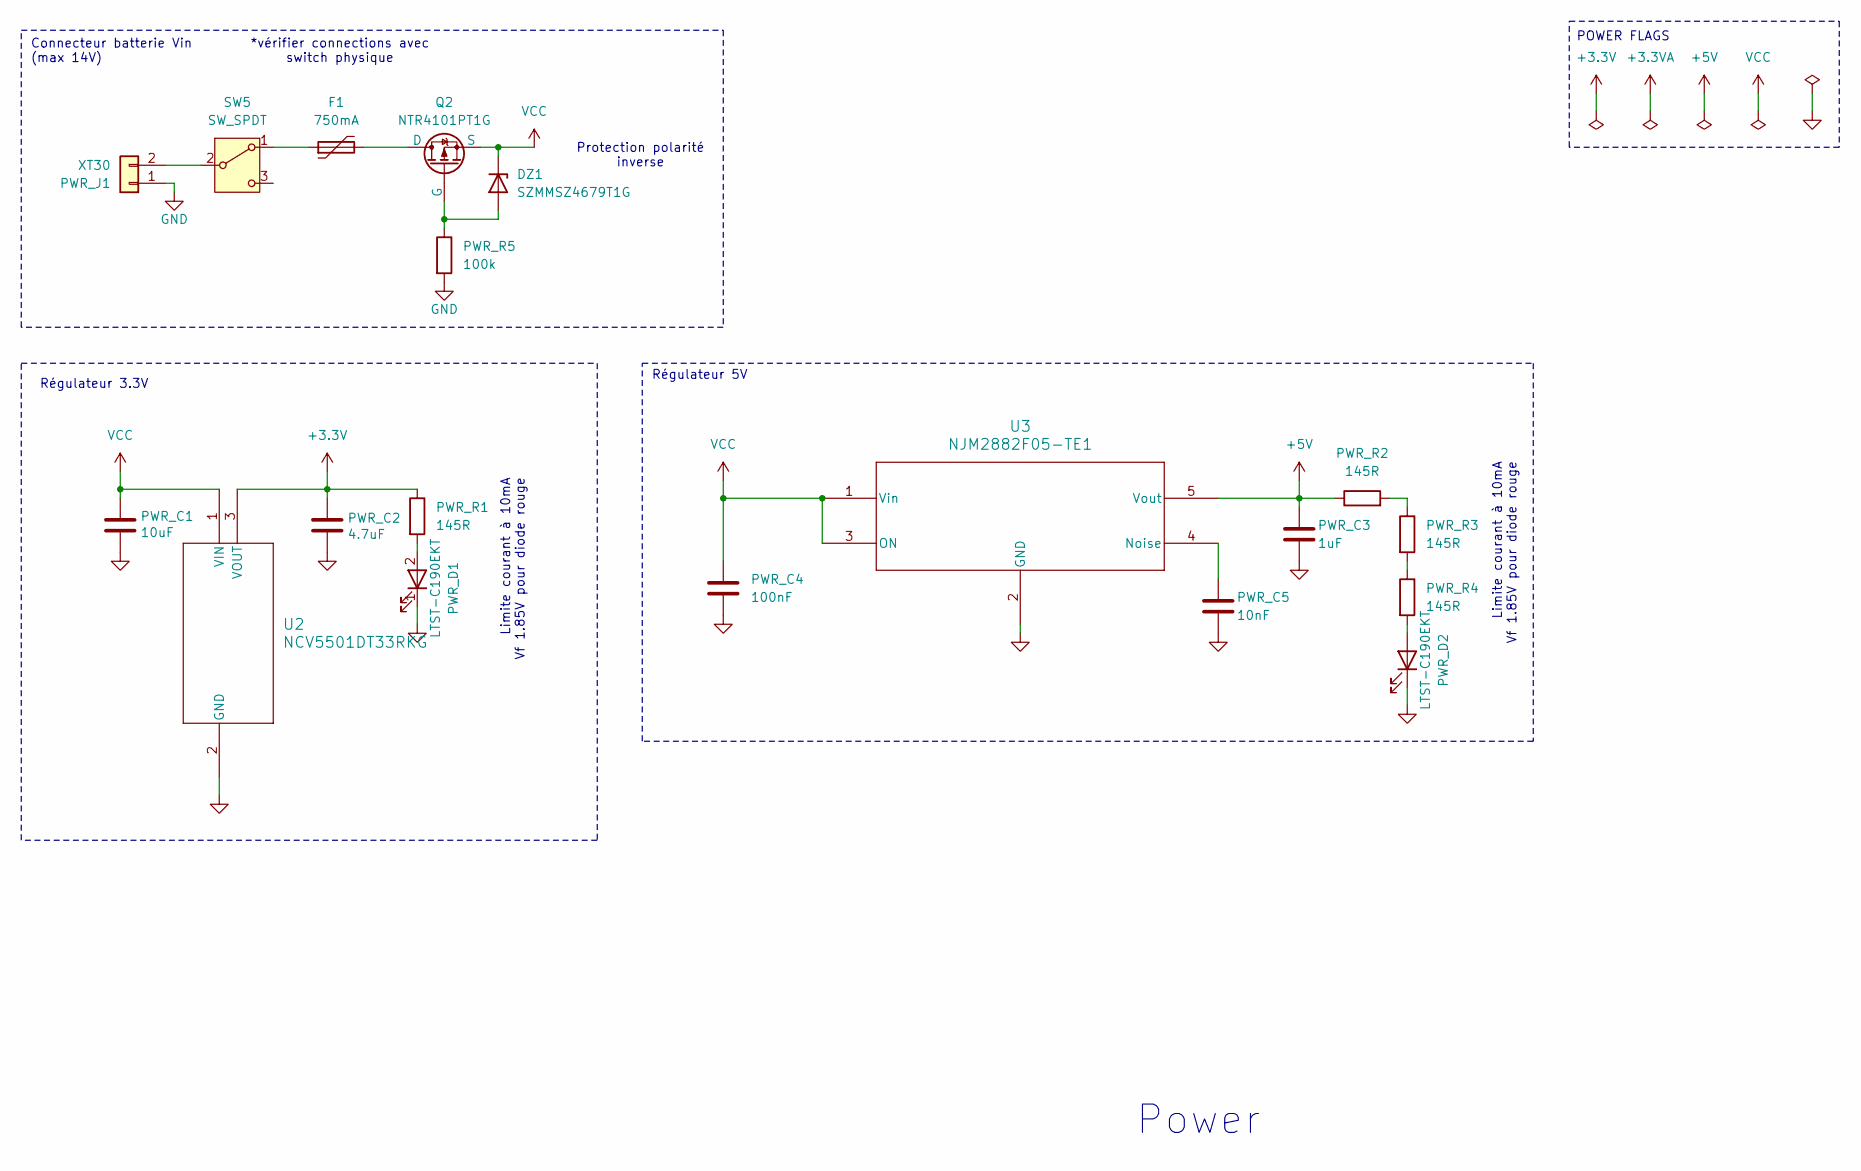
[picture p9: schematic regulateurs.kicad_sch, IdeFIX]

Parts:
DZ1: SZMMSZ4679T1G; D_SOD-123; Digikey SZMMSZ4679T1GOSCT-ND
F1: 750mA; Polyfuse; Digikey 118-MF-NSMF075/13X-2CT-ND
PWR_C1: 10uF; C_1206_3216Metric; Digikey 1276-1804-1-ND
PWR_C2: 4.7uF; C_1206_3216Metric; Digikey 1276-3182-1-ND
PWR_C3: 1uF; C_1206_3216Metric; Digikey 1276-1068-1-ND
PWR_C4: 100nF; C_1206_3216Metric; Digikey 399-C1206C104K5RACTUCT-ND
PWR_C5: 10nF; C_1206_3216Metric; Digikey 311-1174-1-ND
PWR_D1, PWR_D2: LTST-C190EKT; Digikey 516-1422-1-ND
PWR_J1: XT30; AMASS_XT30U-M_1x02_P5.0mm_Vertical; Digikey 1568-10474-ND
PWR_R1, PWR_R2, PWR_R3, PWR_R4: 145R; R_1206_3216Metric; Digikey 2019-RN73H2BTTD1450F100CT-ND
PWR_R5: 100k; R_1206_3216Metric; Digikey 541-100KUCT-ND
Q2: NTR4101PT1G; SOT-23; Digikey NTR4101PT1GOSCT-ND
SW5: SW_SPDT; CS12ANW03_NKK; Digikey 360-2131-ND
U2: NCV5501DT33RKG; DPAK-3_ONS-M; Digikey NCV5501DT33RKGOSCT-ND
U3: NJM2882F05-TE1; SOT-23-5; Digikey 2129-NJM2882F05-TE1CT-ND

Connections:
+3.3V: PWR_C2.1, PWR_R1.1, U2.3 (VOUT); also elsewhere on the board
+5V: PWR_C3.1, PWR_R2.1, U3.5 (Vout); also elsewhere on the board
GND: PWR_C1.2, PWR_C2.2, PWR_C3.2, PWR_C4.2, PWR_C5.2, PWR_D1.1 (K), PWR_D2.1 (K), PWR_J1.1, PWR_R5.2, U2.2 (GND), U3.2 (GND); also elsewhere on the board
unnamed: DZ1.2 (A), PWR_R5.1, Q2.2 (G)
unnamed: PWR_D1.2 (A), PWR_R1.2
unnamed: PWR_D2.2 (A), PWR_R4.2
unnamed: PWR_J1.2, SW5.2 (B)
unnamed: PWR_R2.2, PWR_R3.1
unnamed: PWR_R3.2, PWR_R4.1
unnamed: F1.2, Q2.1 (D)
unnamed: F1.1, SW5.1 (A)
unnamed: PWR_C5.1, U3.4 (Noise)
VCC: DZ1.1 (K), PWR_C1.1, PWR_C4.1, Q2.3 (S), U2.1 (VIN), U3.1 (Vin), U3.3 (ON)

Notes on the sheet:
Limite courant à 10mA Vf 1.85V pour diode rouge
Power
Protection polarité inverse
Connecteur batterie Vin (max 14V)
POWER FLAGS
Régulateur 5V
*vérifier connections avec switch physique
Régulateur 3.3V

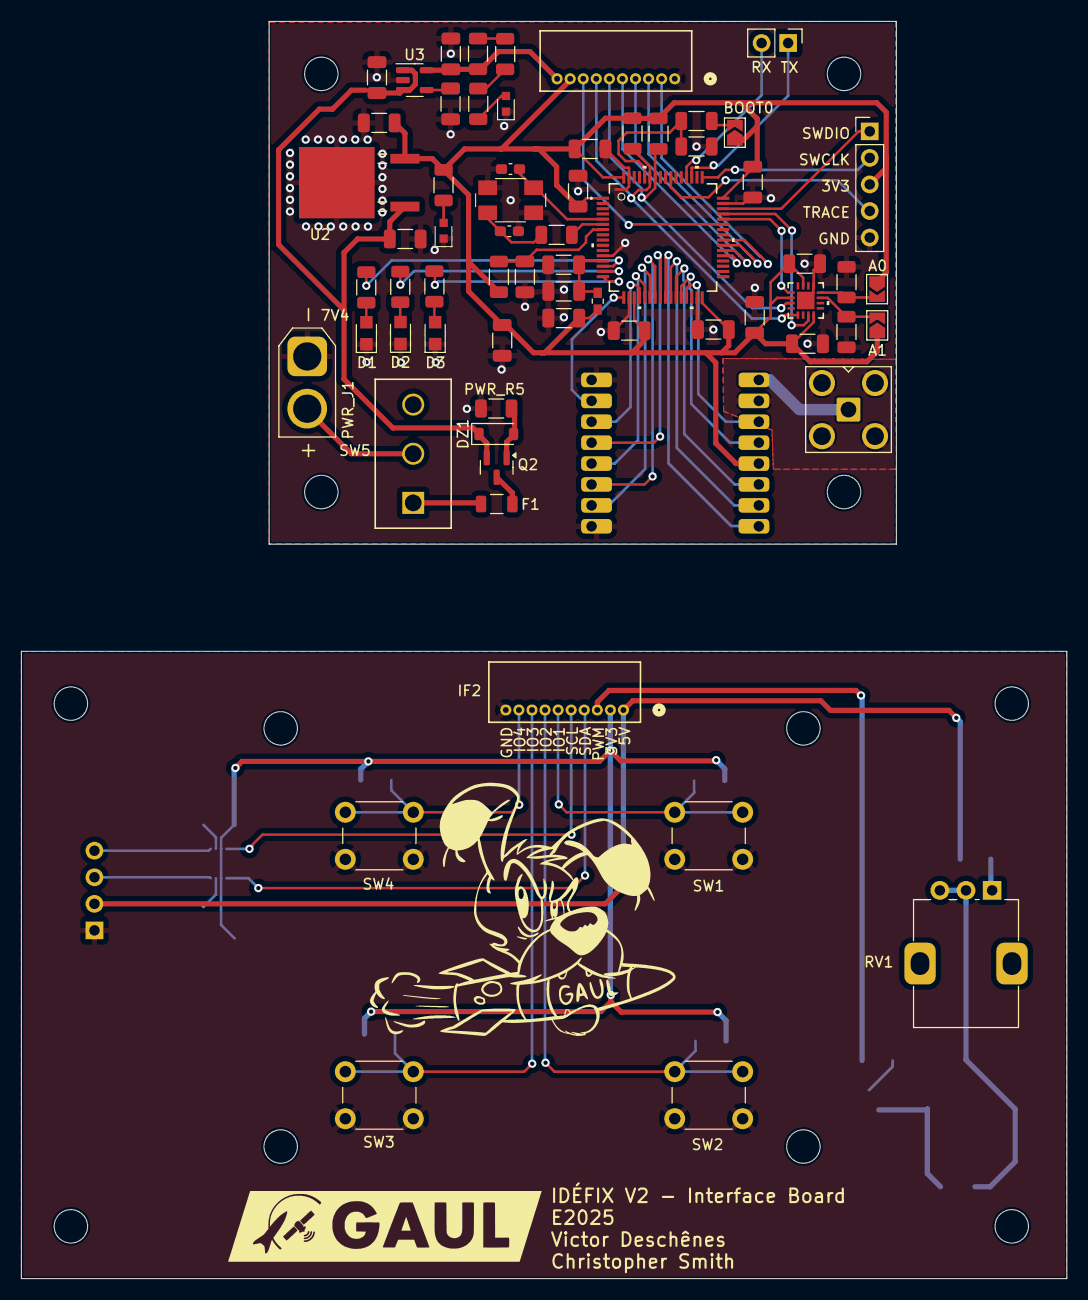
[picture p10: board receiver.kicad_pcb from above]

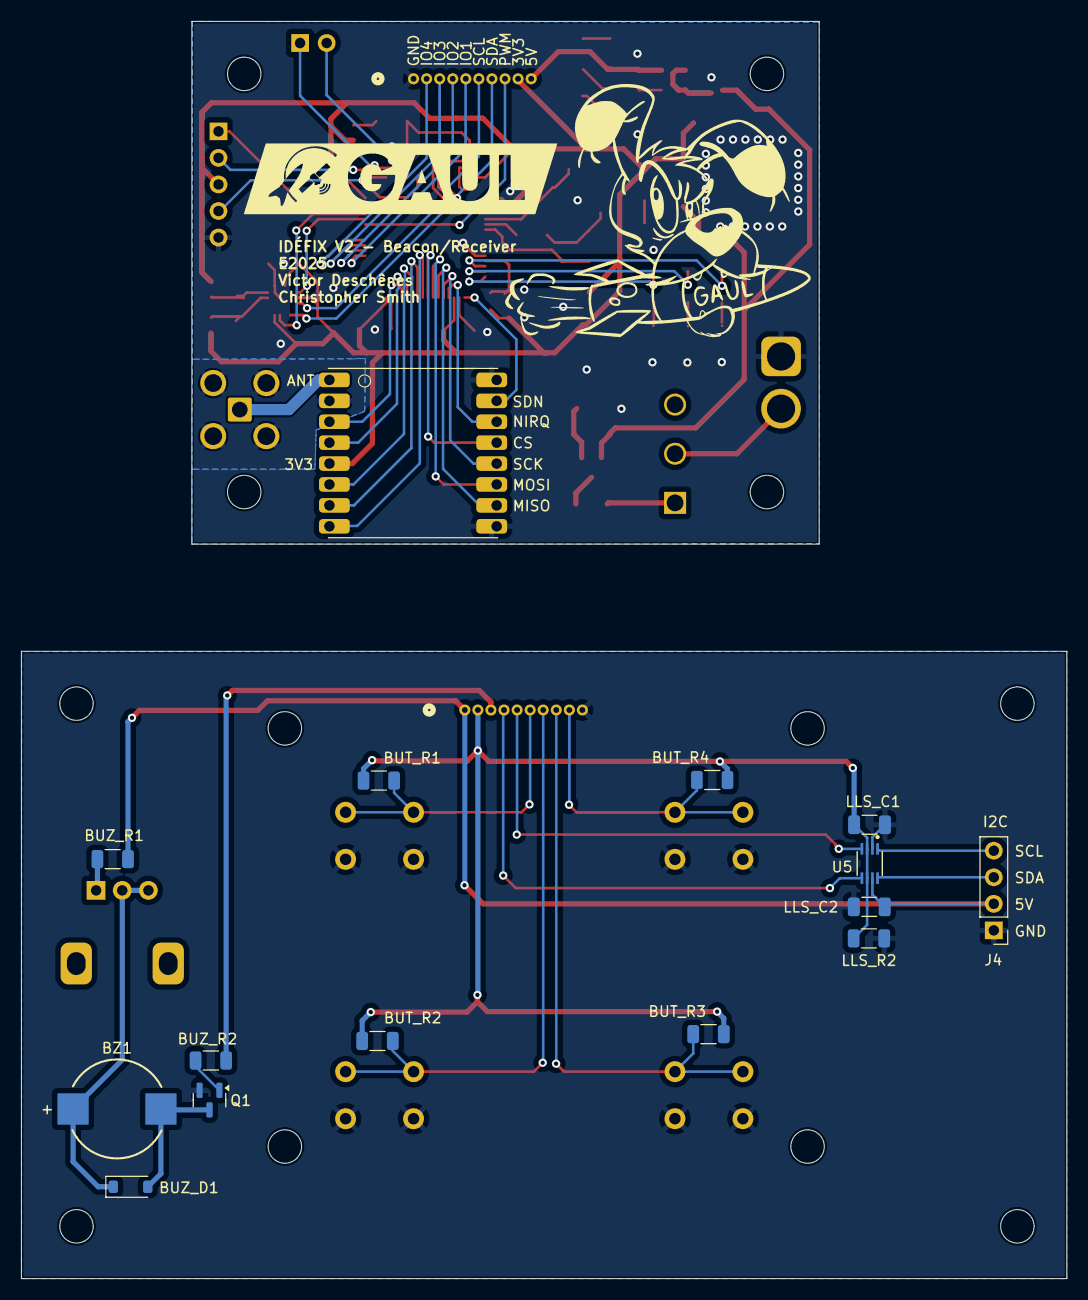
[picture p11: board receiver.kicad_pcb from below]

Board: 2 copper layers, 100.0 x 120.3 mm, 83 parts (15 on the bottom side), 70 nets.

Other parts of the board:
HOLES1, HOLES2: Mounting_holes
HOLES3: Mounting_holes_big

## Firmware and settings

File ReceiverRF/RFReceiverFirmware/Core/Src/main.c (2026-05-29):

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
/* Includes ------------------------------------------------------------------*/
#include "main.h"

I2C_HandleTypeDef hi2c1;

SPI_HandleTypeDef hspi1;

TIM_HandleTypeDef htim1;
TIM_HandleTypeDef htim2;
TIM_HandleTypeDef htim3;
TIM_HandleTypeDef htim4;
TIM_HandleTypeDef htim5;

UART_HandleTypeDef huart4;

void SystemClock_Config(void);
static void MX_GPIO_Init(void);
static void MX_I2C1_Init(void);
static void MX_SPI1_Init(void);
static void MX_TIM1_Init(void);
static void MX_TIM2_Init(void);
static void MX_TIM3_Init(void);
static void MX_TIM4_Init(void);
static void MX_TIM5_Init(void);
static void MX_UART4_Init(void);
/* USER CODE BEGIN PFP */
void PUSH_ISR(uint16_t GPIO_pin);
/* USER CODE END PFP */

/* USER CODE BEGIN 0 */

uint8_t rfm22_interrupt_flag = 0;
uint8_t pushbutton_interrupt_flag = 0;
uint8_t pushbutton_pushed[4] = {0};

void HAL_GPIO_EXTI_Callback(uint16_t GPIO_Pin)
{
	if (GPIO_Pin == RFM_IRQ_Pin) rfm22_interrupt_flag = 1;
	if ((GPIO_Pin == GPIO1_Pin) | (GPIO_Pin == GPIO2_Pin) | (GPIO_Pin == GPIO3_Pin) | (GPIO_Pin == GPIO4_Pin)) PUSH_ISR(GPIO_Pin);
}


void PUSH_ISR(uint16_t GPIO_pin)
{
	pushbutton_interrupt_flag = 1;
	pushbutton_pushed[0] |= (GPIO_pin == GPIO1_Pin);
	pushbutton_pushed[1] |= (GPIO_pin == GPIO2_Pin);
	pushbutton_pushed[2] |= (GPIO_pin == GPIO3_Pin);
	pushbutton_pushed[3] |= (GPIO_pin == GPIO4_Pin);

}


void signal_strenght_bar(char *string, int length, float percent)
{
	if (percent > 100) percent = 100;
	int nb_square = percent * length / 100;
	int nb_dash = length - nb_square;

	for (int i = 0; i < nb_square; i++)
	{
		string[i] = '#';
	}
	for (int i = nb_square; i < length; i++)
	{
		string[i] = '-';
	}
}


void print_menu(RFM22 *dev, I2C_LCD_HandleTypeDef *lcd, uint8_t channel, uint8_t rssi, uint8_t ref_rssi, float latitude, float longitude)
{
	char line[20] = {'-'};
	uint32_t freq = RFM22_get_frequency(dev);
	uint16_t MHz = freq /1e6;
	uint16_t kHz = (freq/1000) % 1000;
	uint16_t Hz = freq % 1000;

	float signal_strenght = 100*((float)rssi-(float)ref_rssi)/((float)ref_rssi+1) + 50;

	lcd_clear(lcd);
	lcd_gotoxy(lcd, 0, 0); // ligne 1
	snprintf(line, 21, "CH:%-3u   %3lu.%03lu.%03lu", channel, MHz, kHz, Hz);
	lcd_puts(lcd, line);
	lcd_gotoxy(lcd, 0, 1); // ligne 2
	snprintf(line, 20, "RSSI:%u", rssi);
	lcd_puts(lcd, line);
	lcd_gotoxy(lcd, 0, 2); // ligne 3
	strcpy(line, "GPS");
	lcd_puts(lcd, line);
	lcd_gotoxy(lcd, 0, 3); // ligne 4
	signal_strenght_bar(line, 20, signal_strenght);
	lcd_puts(lcd, line);

}




/* USER CODE END 0 */

/**
  * @brief  The application entry point.
  * @retval int
  */
int main(void)
{

  /* MCU Configuration--------------------------------------------------------*/

  /* Reset of all peripherals, Initializes the Flash interface and the Systick. */
  HAL_Init();

  /* Configure the system clock */
  SystemClock_Config();

  /* Initialize all configured peripherals */
  MX_GPIO_Init();
  MX_I2C1_Init();
  MX_SPI1_Init();
  MX_TIM1_Init();
  MX_TIM2_Init();
  MX_TIM3_Init();
  MX_TIM4_Init();
  MX_TIM5_Init();
  MX_UART4_Init();
  /* USER CODE BEGIN 2 */
  // init pulsed pins and their respective timers
  Pulse_Pin_Typedef pin1 = PulsePin_init(LED1_GPIO_Port, LED1_Pin, &htim2, TIM_CHANNEL_1);
  Pulse_Pin_Typedef pin2 = PulsePin_init(LED2_GPIO_Port, LED2_Pin, &htim3, TIM_CHANNEL_1);
  Pulse_Pin_Typedef pin3 = PulsePin_init(LED3_GPIO_Port, LED3_Pin, &htim4, TIM_CHANNEL_1);

  // init buzzer and its watch timer
  buzzer_init(&htim1, TIM_CHANNEL_3, &htim5, TIM_CHANNEL_1);

  // init lcd
  I2C_LCD_HandleTypeDef lcd;
  lcd.hi2c = &hi2c1;
  lcd.address = 0x27<<1;
  lcd_init(&lcd);
  lcd_clear(&lcd);

  //init rfm22
  RFM22 rfm22 = {
		  .SPIx = &hspi1,
		  .cs_port = RFM_CS_GPIO_Port,
		  .cs_pin = RFM_CS_Pin,
		  .snd_port = RFM_SDN_GPIO_Port,
		  .snd_pin = RFM_SDN_Pin,
		  .nirq_port = RFM_IRQ_GPIO_Port,
		  .nirq_pin = RFM_IRQ_Pin,
		  .gpio_port_1 = RFM_GPIO1_GPIO_Port,
		  .gpio_pin_1 = RFM_GPIO1_Pin,
		  .gpio_port_2 = RFM_GPIO2_GPIO_Port,
		  .gpio_pin_2 = RFM_GPIO2_Pin,
		  .gpio_port_3 = RFM_GPIO3_GPIO_Port,
		  .gpio_pin_3 = RFM_GPIO3_Pin
  };

  RFM22_init(&rfm22, &rfm22_confs);
  uint8_t channel = 0;
  /* USER CODE END 2 */

  /* Infinite loop */
  /* USER CODE BEGIN WHILE */


  //global vars
  RFM22_channel(&rfm22, channel);
  print_menu(&rfm22, &lcd, 0, 0, 0, 0, 0);
  const char* packet_str = "VE2VQW";
  uint8_t packet[8];
  memcpy(packet,packet_str, 6);    // copy packet_str to packet without '\0'
  uint8_t rssi = 0;
  uint8_t ref_rssi = 0;
  uint32_t freq;
  float latitude = 0;
  float longitude = 0;
  uint8_t spi_rx[1] = {0};

  while (1)
  {
    /* USER CODE END WHILE */

    /* USER CODE BEGIN 3 */

#ifdef TRANSMIT
	  RFM22_transmit(&rfm22, packet, 8);
	  uint32_t tick = HAL_GetTick();
	  while (HAL_GetTick() - tick < 1000);
#endif

#ifdef RECEIVE
	  RFM22_SPI_read(&rfm22, RH_RF22_REG_07_OPERATING_MODE1, spi_rx, 1);
	  if (!(spi_rx[0] & RH_RF22_RXON))
	  {
		  RFM22_rx_mode(&rfm22);
      }
#endif


	  //handle rfm22 interrupts
	  if (rfm22_interrupt_flag || (!HAL_GPIO_ReadPin(RFM_IRQ_GPIO_Port, RFM_IRQ_Pin)))
#ifdef TRANSMIT
	  {
		  rfm22_interrupt_flag = 0;
		  uint8_t interrupts[] = {0, 0};
		  RFM22_SPI_read(&rfm22, RH_RF22_REG_03_INTERRUPT_STATUS1, interrupts, 2);

		  //pk sent interrupt
		  if (interrupts[0] & RH_RF22_IPKSENT)
		  {
			  PulsePin(pin1, 100);
		  }

		  //tx FIFO full
		  if (interrupts[0 & RH_RF22_ITXFFAFULL])
		  {
			  RFM22_clr_tx_FIFO(&rfm22);
		  }
	  }
#endif

#ifdef RECEIVE
	  {
		  rfm22_interrupt_flag = 0;
		  uint8_t interrupts[] = {0, 0};
		  RFM22_SPI_read(&rfm22, RH_RF22_REG_03_INTERRUPT_STATUS1, interrupts, 2);


		  //pk received
		  if (interrupts[0] & RH_RF22_IPKVALID)
		  {
			  PulsePin(pin1, 100);
			  uint8_t lenght = RFM22_available(&rfm22);

			  // GPS routine
			  rssi = RFM22_get_RSSI(&rfm22);
			  RFM22_read_rx(&rfm22, packet, 8);
			  latitude = 0; // à vérifier, supposé transformer en float direct
			  longitude = 0;

			  // rssi routine
			  int16_t rssi_dif = rssi - ref_rssi;
			  freq = 3000 + 200*rssi_dif;
			  buzzer_start(freq, 200);
			  print_menu(&rfm22, &lcd, channel, rssi, ref_rssi, latitude, longitude);
		  }

		  //rx FIFO full
		  if (interrupts[0] & RH_RF22_IRXFFAFULL)
		  {
			  //read last received
			  //RFM22_clr_rx_FIFO(&rfm22);
			  PulsePin(pin3, 100);
		  }

		  //valid preamble
		  if (interrupts[1] & RH_RF22_IPREAVAL)
		  {
		  }

		  //inval preamble
		  if (interrupts[1] & RH_RF22_IPREAINVAL)
		  {
			  PulsePin(pin2, 100);
		  }
	  }


	  if (pushbutton_interrupt_flag)
	  {
		  pushbutton_interrupt_flag = 0;

		  if (pushbutton_pushed[0]) // channel up
		  {
			  channel++;
			  RFM22_channel(&rfm22, channel);
			  print_menu(&rfm22, &lcd, channel, rssi, ref_rssi, latitude, longitude);
		  }
		  if (pushbutton_pushed[1]) // channel down
		  {
			  channel--;
			  RFM22_channel(&rfm22, channel);
			  print_menu(&rfm22, &lcd, channel, rssi, ref_rssi, latitude, longitude);
		  }
		  if (pushbutton_pushed[2]) // zero
		  {
			  ref_rssi = rssi;
		  }
		  if (pushbutton_pushed[3])
		  {

		  }

		  pushbutton_pushed[0] = 0;
		  pushbutton_pushed[1] = 0;
		  pushbutton_pushed[2] = 0;
		  pushbutton_pushed[3] = 0;
	  }
#endif
  }
  /* USER CODE END 3 */
}

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


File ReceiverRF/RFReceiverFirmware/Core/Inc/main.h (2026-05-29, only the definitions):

#define LED1_Pin GPIO_PIN_0
#define LED1_GPIO_Port GPIOA
#define LED2_Pin GPIO_PIN_1
#define LED2_GPIO_Port GPIOA
#define LED3_Pin GPIO_PIN_2
#define LED3_GPIO_Port GPIOA
#define RFM_SDN_Pin GPIO_PIN_3
#define RFM_SDN_GPIO_Port GPIOA
#define RFM_IRQ_Pin GPIO_PIN_4
#define RFM_IRQ_GPIO_Port GPIOA
#define RFM_IRQ_EXTI_IRQn EXTI4_IRQn
#define RFM_CS_Pin GPIO_PIN_4
#define RFM_CS_GPIO_Port GPIOC
#define RFM_GPIO3_Pin GPIO_PIN_5
#define RFM_GPIO3_GPIO_Port GPIOC
#define RFM_GPIO2_Pin GPIO_PIN_0
#define RFM_GPIO2_GPIO_Port GPIOB
#define RFM_GPIO1_Pin GPIO_PIN_1
#define RFM_GPIO1_GPIO_Port GPIOB
#define RFM_GPIO5_Pin GPIO_PIN_2
#define RFM_GPIO5_GPIO_Port GPIOB
#define RFM_GPIO4_Pin GPIO_PIN_10
#define RFM_GPIO4_GPIO_Port GPIOB
#define GPIO1_Pin GPIO_PIN_6
#define GPIO1_GPIO_Port GPIOC
#define GPIO1_EXTI_IRQn EXTI9_5_IRQn
#define GPIO2_Pin GPIO_PIN_7
#define GPIO2_GPIO_Port GPIOC
#define GPIO2_EXTI_IRQn EXTI9_5_IRQn
#define GPIO3_Pin GPIO_PIN_8
#define GPIO3_GPIO_Port GPIOC
#define GPIO3_EXTI_IRQn EXTI9_5_IRQn
#define GPIO4_Pin GPIO_PIN_9
#define GPIO4_GPIO_Port GPIOC
#define GPIO4_EXTI_IRQn EXTI9_5_IRQn
#define MLX_INT_TRIG_Pin GPIO_PIN_11
#define MLX_INT_TRIG_GPIO_Port GPIOA
#define MLX_INT_Pin GPIO_PIN_12
#define MLX_INT_GPIO_Port GPIOA
#define RECEIVE // TRANSMIT or RECEIVE				METTRE CETTE LIGNE EN COMMENTAIRE POUR PASSER EN MODE TRANSMIT et inversement pour le mettre en mode RECEIVE
#define TRANSMIT // TRANSMIT

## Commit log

2025-03-03 correction mineure, logo Idefix, commande PCBWAY
    [capteurs.kicad_sch, commande.xlsx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]
2025-03-03 changement cristal
    [406C35D08M00000.STEP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]
2025-03-07 changement vers footprint 1206
    [IOinterface.kicad_sch, capteurs.kicad_sch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]
2025-03-07 changement BOM et choix nouvelles pièces 1206
    [IOinterface.kicad_sch, bom.csv, capteurs.kicad_sch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]
2025-03-08 Ajout date, nom et version
    [receiver.kicad_pcb]
2025-03-08 Auto stash before checking out "origin/ODB"
    nom et commande
    [receiver.kicad_pcb]
2025-04-11 firmware oscillateur interne :(
    [IOinterface.kicad_sch, commande.xlsx, receiver.kicad_pcb]
2025-04-15 firmware dossiers gaul drivers
2025-04-15 SPI rfm fonctionnel
2025-06-01 lcd working, buzzer marche avec fix temporaire, IO fonctionnels
    [RFM22.c, RFReceiverFirmware.ioc, main.c]
2025-07-09 ideFIX v2 fix schematic, layout
    [530481010.stp, CS12ANW03.stp, IOinterface.kicad_sch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]
2025-07-10 revision schematic before tracing
    [IOinterface.kicad_sch, capteurs.kicad_sch, receiver.kicad_pcb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]
2025-07-11 Final layout and routing
    [receiver.kicad_pcb]
2025-07-14 finished silkscreen and added logos
    [receiver-B_Adhesive.gbr, receiver-B_Courtyard.gbr, receiver-B_Cu.gbr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]
2025-07-15 fix zener diode footprint, thermal relief on SMA conn, more work on silkscreen
    [capteurs.kicad_sch, receiver.kicad_pcb, receiver.kicad_sch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]
2025-07-22 3.2mm holes, XT30 connector, add polyfuse, minor fixes
    [IOinterface.kicad_sch, XT30-M_m.ver.STEP, capteurs.kicad_sch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]
2025-08-04 Refactor timer handling and add TRANSMIT/RECEIVE definition macros
    [IOinterface.kicad_sch, capteurs.kicad_sch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]
2026-05-18 (ajout) ajout de la fonction de modification de fréquence + du code d'identification

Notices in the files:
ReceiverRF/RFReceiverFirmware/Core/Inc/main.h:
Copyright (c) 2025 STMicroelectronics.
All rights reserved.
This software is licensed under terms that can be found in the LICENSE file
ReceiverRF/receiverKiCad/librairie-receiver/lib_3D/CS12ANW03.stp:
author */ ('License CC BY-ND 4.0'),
